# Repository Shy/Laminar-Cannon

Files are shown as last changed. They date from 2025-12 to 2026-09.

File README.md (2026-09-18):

# Laminar Cannon

A person-tracking air purifier that automatically aims filtered air at people using computer vision and pan/tilt servos.

## Highlights

- 🎯 Real-time person tracking with YOLO11 pose detection, aimed at the head
- 🌀 Automatically directs HEPA-filtered air toward detected people
- 🤖 Distributed workflow orchestration with Temporal
- 🎮 Raspberry Pi Zero 2 W drives the servos over I2C
- 📹 Works with a standard Pi Camera Module

## Overview

The Laminar Cannon detects people in real time and mechanically aims fans through a HEPA filter to direct clean air at them. A worker on a laptop runs pose detection while a Raspberry Pi captures frames and drives pan/tilt servos, with Temporal coordinating the two.

Inspired by PC fan powered airpurifiers, this project started with an excellent base by forking from the [Nukit Laminar Cannon](https://github.com/opennukit/Nukit-Laminar-Cannon/). This is a from-scratch build using off-the-shelf components, that I mostly had in my apartment, using python person detection rather than expensive camera eqipment. Nukit has a lot of great information about why this style of airpurifier is effective and I'll defer to them, rather than repeating it.

**Cost:** ~$180-230 in parts

## How It Works

1. A long-running `TrackPerson` workflow loops, starting one `TrackFrame` child workflow per frame
2. The Pi captures a 768x432 frame and returns it as JPEG bytes
3. The laptop runs YOLO11-pose and reports where the person's head is, as an offset from frame centre
4. The workflow converts that offset into a relative servo move
5. The Pi applies the move and reads the resulting angles back off the servo driver

Roughly 1 second per frame when the camera is already centred, 2 seconds when it has to move.

Pose detection is used rather than plain face or body detection so the camera can aim at the **head** specifically. A standing person's bounding-box centre sits around the waist, which frames them with their head near the top edge of the shot.

### Why Temporal?

The Pi Zero 2 W can't run YOLO detection locally - it would take 10+ seconds per frame. By offloading detection to a Temporal workflow on a more powerful machine:

- **Pi stays lightweight** - it only serves camera and servo activities
- **Fast detection** - YOLO runs on laptop hardware in about 100 ms
- **Scalable** - add more Pi units tracking different areas, all using the same detection worker
- **Reliable** - a failed frame costs one frame, not the tracker; the loop counts it and carries on

One detection worker can support dozens of tracking units.

Worth being honest about the fit: Temporal adds tens to hundreds of milliseconds per activity, so this is the wrong tool for a tight, high-rate control loop. At roughly one frame per second it fits comfortably, and durable execution across two very different machines is the interesting part.

## Hardware

- Raspberry Pi Zero 2 W + Camera Module 3 (IMX708)
- Adafruit 16-Channel PWM Servo Bonnet (PCA9685, I2C `0x40`)
- 1x 25 kg-cm servo (tilt) and 1x 20 kg-cm 270° servo (pan)
- 2x high static pressure 120 mm 12 V fans (>2.2 mm H₂O static pressure)
- 12 V to 5-6 V buck converter, **rated 8 A or more**
- 12 V / 5 A power supply
- Levoit Core 200S HEPA Filter

### Things that will bite you

**Size the buck converter properly.** Each servo can pull 2-3 A stalled. A common LM2596 module is 2-3 A total and will brown out mid-sweep - the Pi reboots or the I2C bus drops out. Use an XL4016-class module instead, and put a 1000 µF capacitor across `V+`/`GND` at the bonnet.

**Never feed 12 V to the bonnet's `V+`.** These servos are rated 4.8-6.8 V. Over-volting them causes them to hunt and shake while holding position, which looks exactly like a software problem and is not.

**Clamp the base.** These servos produce far more torque than a light camera needs, and the surplus goes into the mount as reaction torque. A wide fast swing will tip a free-standing rig over. Travel is capped at ±45° per axis in software and the slew rate is deliberately limited, but neither substitutes for clamping it down. Don't ask me how I know. Twice.

### Wiring

Servo power comes from the buck converter; the fans run straight off 12 V. One supply feeds everything.

```
12V 5A supply ──┬── 12V ─────────────────── Fan 1 + / Fan 2 +
                │                           (always on, not switched)
                ├── buck 12V→5-6V (8A+) ─── Bonnet V+ / GND
                │                           + 1000µF cap at the bonnet
                └── GND ────────────────┬── common ground
                                        └── Fan 1 - / Fan 2 -

Pi USB 5V ────── Raspberry Pi ── I2C (GPIO 2/3) ── Servo Bonnet
                      │                                  ├── Ch 0 ──► Tilt servo
                      │                                  └── Ch 1 ──► Pan servo
                      └── CSI ── Camera Module 3
```

Servo connectors are the usual three wires: **brown → GND, red → V+, yellow → PWM**. The bonnet's header rows are silkscreened `GND` / `V+` / `PWM`; line the brown wire up with `GND`. Getting red and brown swapped kills a servo instantly.

**Channel 0 is tilt and channel 1 is pan**, which is the opposite of what you might expect. That mapping came from commanding each axis on the assembled rig and seeing which way the picture moved, so check yours rather than trusting this.

## Software

Two workers. The laptop hosts both workflows plus pose detection; the Pi serves only camera and servo activities. They find each other through Temporal, so they never need to reach each other directly - which also means conference wifi client isolation can't break it.

### Prerequisites

- Python 3.13 on both machines (pinned in `.python-version`)
- [uv](https://docs.astral.sh/uv/) on both machines
- A Temporal Cloud namespace and API key, or adapt `src/purifier/client.py` for a local dev server
- I2C enabled on the Pi: `sudo raspi-config` → Interface Options → I2C, then reboot
- `rpicam-apps` on the Pi (ships with Raspberry Pi OS). Confirm the camera with `rpicam-still --list-cameras`

### Configuration

```bash
cp .env.example .env
```

```bash
TEMPORAL_ADDRESS=your-namespace.tmprl.cloud:7233
TEMPORAL_NAMESPACE=your-namespace.your-account
TEMPORAL_API_KEY=your-api-key
```

The same `.env` is needed on the Pi; `just pi-deploy` copies it across. It is gitignored - keep it that way.

Set the Pi's hostname at the top of the `justfile` (`pi_host`), or add a `Host` entry to your `~/.ssh/config`.

### Running

On the laptop:

```bash
just sync          # install deps, including torch and ultralytics
just worker-mac    # hosts both workflows and pose detection
```

On the Pi, from the laptop:

```bash
just pi-bootstrap          # one time: installs uv
just pi-deploy             # rsync the code and sync dependencies
just pi-worker-fg          # run the worker in the foreground
```

For something that survives a reboot, install the systemd unit instead (needs sudo on the Pi):

```bash
just pi-install-service
just pi-logs
```

Then drive the loop from the laptop:

```bash
just frames 1      # a single frame, the quickest end-to-end check
just start         # run continuously
just status        # frames processed, last action, current state
just stop          # finish the current frame and exit cleanly
```

`just stop` signals the workflow rather than terminating it, so the frame in flight completes and the servos are never abandoned mid-ramp.

## Calibrating the hardware

Check the camera on its own:

```bash
python3 camera_test.py --list          # confirm the sensor is detected
python3 camera_test.py                 # capture to ~/captures/
python3 camera_test.py --rotation 0    # raw sensor orientation
```

The camera module is mounted inverted here, so captures are rotated 180° in the libcamera pipeline. If yours is the right way up, set `CAPTURE_ROTATION_DEGREES` to `0` in `src/purifier/hardware.py`.

Servos, from the laptop:

```bash
just pi-servo-read           # angles read back off the PCA9685 registers
just pi-servo-centre         # centre both axes
just pi-servo-nudge 10 0     # relative move: pan +10°, tilt 0
just pi-servo-release        # stop driving, servos go limp
```

To establish your own direction signs: capture a frame, nudge one axis by a known amount, capture again, and see which way the picture moved. If the camera turns away from the person instead of toward them, flip `PAN_DIRECTION` or `TILT_DIRECTION` in `src/purifier/shared.py`.

The tracking gain lives in the same file. `PROPORTIONAL_GAIN` is deliberately below 1.0 so the camera undershoots and settles; at or above 1.0 it hunts around the target. `PAN_DEGREES_PER_OFFSET` and `TILT_DEGREES_PER_OFFSET` are measured on this rig and will differ on yours.

## Tests

```bash
just check    # ruff and mypy
uv run pytest
```

The workflow tests run against a real Temporal test server with stubbed hardware, so they exercise the actual serialisation path. Detection tests need a fixture image with a person in it under `tests/fixtures/`; they skip cleanly when it is absent.

## Project layout

```
3D/                          CAD for the printed parts (STEP and 3MF)
src/purifier/
  workflows.py               TrackPerson parent loop, TrackFrame child, control law
  activities_pi.py           capture_frame, move_servos, read_servo_angles
  activities_mac.py          detect_person (YOLO11-pose)
  camera.py                  persistent rpicam-still process
  pca9685.py                 servo driver over smbus2
  hardware.py                servo calibration and camera settings
  shared.py                  data contracts and tuning constants
  tracker.py                 start / stop / status CLI
  servo_tool.py              servo diagnostics and calibration CLI
camera_test.py               standalone camera check
deploy/                      systemd unit for the Pi worker
DESIGN.md                    why things are built the way they are
```

`DESIGN.md` is worth a read before changing anything: it records the measurements behind the tuning constants and several traps that cost real debugging time.

## Known gaps

- **Fan control was dropped.** An earlier version drove the fans from the Pi's hardware PWM and switched them off five seconds after the last detection. The current code doesn't touch the fans at all - they're wired straight to 12 V and run constantly. Re-adding this needs a MOSFET on a Pi PWM pin, since the PCA9685 shares one prescaler across all channels and can't produce the 25 kHz a 4-wire fan expects.
- The camera's focus is fixed, set by `LENS_POSITION_DIOPTRES`. Autofocus needs about 2.5 seconds to lock, which doesn't fit the loop.
- Nobody detected means hold position. There's no search pattern or return-to-centre.
- With several people in frame it tracks the largest bounding box, which is effectively the nearest person. Targets can switch between frames.

## License

Matching the original [Nukit Laminar Cannon](https://github.com/opennukit/Nukit-Laminar-Cannon/). This is also a [GPL-3 project](https://www.gnu.org/licenses/gpl-3.0.en.html).
Feel free to fork and adapt!

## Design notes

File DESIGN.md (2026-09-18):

# Person-Tracking Camera on Temporal

A teaching artifact: a Raspberry Pi Zero 2 W aims a camera at whoever is
standing in front of it, with a MacBook doing the person detection and
Temporal Cloud coordinating the two.

The point is to show durable execution across heterogeneous workers - a
constrained ARM device and a laptop with a GPU - not to build a fast tracker.
Temporal adds tens to hundreds of milliseconds per activity, so a tight
control loop is the wrong use of it. At roughly one frame per second, it fits.

## Architecture

```
Temporal Cloud (API key auth)
  |
  +-- workflow TrackPerson  (parent loop)         queue: purifier-mac
        |  continue-as-new every 50 frames
        |
        +-- workflow TrackFrame  (one per frame)  queue: purifier-mac
              |
              +-- activity capture_frame   queue: purifier-pi   (Pi)
              +-- activity detect_person   queue: purifier-mac  (Mac, YOLO11-pose)
              +-- activity move_servos     queue: purifier-pi   (Pi)
```

A long-running parent loop drives one child workflow per frame. Both
workflows are hosted on the MacBook worker; the Pi serves only camera and
servo activities, which keeps the workflow sandbox off a 415 MB board.

The child-per-frame split is for legibility. Activities inline in the parent
produced a history of hundreds of interleaved events that was unreadable in
the UI; now the parent shows one line per frame and each child holds a short,
self-contained history of exactly three activities. Measured cost of the
split: 0.07-0.14 s per frame, far less than feared.

Servo position is not carried across frames or generations. It is read back
from the PCA9685 registers inside the move activity, so the hardware stays
the single source of truth.

### Superseded: a Schedule per frame

The loop began as a Temporal Schedule firing one `TrackPerson` execution per
tick. It worked, but per-frame workflow startup plus waiting for the next
tick boundary cost about a second a frame and bought nothing. A parent loop
removes both. The Schedule tooling is kept in `purifier.schedule` so the
leftover paused Schedule in Cloud can be inspected or deleted.

## Hardware

| Channel | Device | Axis | Range | Notes |
| --- | --- | ---- | ----- | ----- |
| 0 | 25 kg-cm servo | pan | 180 deg | Stronger servo carries the tilt assembly |
| 1 | 20 kg-cm servo | tilt | 270 deg | Only ~90 deg of travel is used |
| - | Camera Module 3 (IMX708) | - | - | CSI, manual fixed focus |
| 15 | unused | - | - | 12 V fan is wired direct, not switched |

Both servos are wildly overspecified for a ~5 g camera. Torque is irrelevant
here; backlash and deadband are the real problems, so expect jitter and
overshoot at small angles.

## Decisions

| Decision | Choice | Why |
| --- | --- | --- |
| Loop shape | One workflow per frame, via a Schedule | Each history is small and readable end to end; teaches Schedules |
| Overlap policy | `SKIP` | Self-tuning, can never back up. `ALLOW_ALL` would be a bug: two runs would read the same start angles and both apply a delta |
| Servo state | Read back from PCA9685 registers | Keeps each run genuinely stateless. Needs a homing step when registers read zero |
| Capture | `--mode 2304:1296 --width 768 --height 432` | Full sensor field of view at ~691 ms and 33 KB. The naive 640x480 silently crops to half the sensor width |
| Focus | Manual fixed (`--lens-position`) | Faster and deterministic; YOLO does not need a sharp frame. Autofocus needed 2.5 s to lock |
| Transport | JPEG bytes in the Temporal payload | ~33 KB, ~44 KB base64. Small enough that history stays readable |
| Detection | YOLO11-pose on the Mac | Keypoints let it aim at the head, not the bbox center, which frames a standing person badly |
| Target choice | Largest bounding box; no-op when none | Deterministic per frame, needs no state. "Faces whoever is nearest" |
| Control law | Proportional, `Kp ~= 0.5`, 5% deadband, max-step clamp | Deliberately undershoots so a ~1.5 s loop converges without oscillating. Needs no lens FOV data |
| Coordination | Temporal Cloud, API key auth | Immune to conference WiFi client isolation - neither machine needs to reach the other |
| Retries | 3 attempts per activity, 30 s `workflow_execution_timeout` | `SKIP` plus infinite retries deadlocks silently: one stuck run makes every later tick skip |
| Pi deploy | rsync + systemd unit | Worker survives reboots; a dead worker otherwise looks like a Temporal failure |

## Measured, not guessed

On the Pi, two passes, `rpicam-still` with a fresh process each time:

| Capture | Sensor crop | Time | Size |
| --- | --- | ---- | ---- |
| 640x480, naive | 2304x1728 (half width) | ~750 ms | 34 KB |
| 640x360, naive | 3072x1728 (67%) | ~691 ms | 22 KB |
| 640x360 `--mode 2304:1296` | full 4608x2592 | ~697 ms | 23 KB |
| 768x432 `--mode 2304:1296` | full 4608x2592 | ~691 ms | 33 KB |
| 640x360 `--mode 4608:2592` | full | ~1739 ms | 21 KB |
| 640x480, continuous AF, 2 s settle | - | ~2450 ms | 34 KB |

Roughly 600 ms is the floor - that is process startup plus camera open, paid
once per capture.

Per-frame budget: ~700 ms capture, 20-50 ms detection warm, 200-500 ms servo
move, plus Cloud round trips. Expect ~1.5-2 s per frame, so `SKIP` settles on
an effective ~2 s cadence.

## Constraints

- **Never capture while the servos are moving.** Satisfied by construction:
  the activities are sequential within one run, and `SKIP` means runs never
  overlap.
- **Pi RAM is 415 MB total.** Nothing else runs on it. `temporalio` has
  aarch64 wheels, so no Rust compile.
- **Python pinned to 3.13.5 on both sides.** Matches the Pi's system Python
  and sidesteps whether PyTorch has 3.14 wheels.
- **torch must never land on the Pi.** Hence two extras rather than one
  dependency list.
- **The API key lives on the Pi's SD card.** Re-provisioning is part of the
  cost of losing a card.

## Layout

```
pyproject.toml              # requires-python 3.13.5; extras: pi, mac
.env.example                # TEMPORAL_ADDRESS / _NAMESPACE / _API_KEY
src/purifier/
  shared.py                 # dataclasses for activity arguments and returns
  activities_pi.py          # capture_frame, move_servos
  activities_mac.py         # detect_person
  workflows.py              # TrackPerson
  worker_pi.py
  worker_mac.py
  schedule.py               # create or update the Schedule
servo_test.py               # standalone hardware check
camera_test.py              # standalone camera check
```

## Idempotency note worth keeping

If `move_servos` fails partway through a ramp, the servos are left at an
intermediate angle - and that is fine. The next frame reads the actual angles
back off the PCA9685 and computes a fresh delta from wherever they really are.
The hardware is the source of truth, so a partial failure self-corrects on the
next tick rather than needing compensation.

## Found during implementation

Two bugs that the design did not anticipate, both worth keeping in mind:

**EXIF orientation is load-bearing for detection, not cosmetic.** The pose
model is trained on upright people. The same frame scores 0.92 confidence
upright and detects *nothing at all* sideways. Worse, `PIL.Image.open`
ignores the EXIF orientation tag, so embedding the tag at capture is not
enough - `ImageOps.exif_transpose` has to be applied before inference. There
is a regression test for this, because every other part of the system looks
perfectly healthy when it breaks.

A second-order trap: `exif_transpose` swaps width and height for a 90 degree
rotation, so offsets must be normalised against the decoded image's
dimensions, not the ones the Pi reported. Using the Pi's values scales both
axes by the wrong divisor.

**ultralytics monkeypatches `PIL.Image.open`.** Its replacement raises
`ModuleNotFoundError` for the optional `pi_heif` package when a decode fails,
rather than PIL's `UnidentifiedImageError`. Catching only PIL's exception let
that escape as an unexpected error, which Temporal treats as retryable - so a
corrupt payload would burn all three attempts instead of failing fast. The
decode handler is deliberately broad for this reason.

## Hardware lessons, learned the hard way

**Servos were being fed ~11 V against a 4.8-6.8 V rating.** The symptom was
the pan axis shaking while holding position. Two software theories were
plausible and both were wrong: ramp-step quantization (real, and worth fixing
anyway) and control-loop gain. Neither was the cause. Dropping the supply to
5 V stopped it immediately.

Worth remembering as a diagnostic order: servo jitter *while holding* points
at power or the servo, not at the code. Jitter *during motion* is the one that
points at the ramp.

**Reaction torque tipped the stand over.** These servos produce vastly more
torque than a 5 g camera needs, and a fast wide swing puts the surplus into
the mount. Fixed by clamping the base, restricting travel to +/-45 degrees per
axis, and cutting the slew rate.

**The axes were not what the design assumed.** Channel 0 turned out to be
tilt and channel 1 pan, and only one of the two directions was positive. All
three facts came from commanding an axis and looking at the resulting frame -
none of them were knowable in advance.

## Latency, measured

Per-frame breakdown on the parent/child architecture, after the fixes below:

| Stage | Time |
| ----- | ---- |
| `capture_frame` | 0.60 s |
| `detect_person` (warm) | 0.10 s |
| `move_servos` (when needed) | 0.56-0.70 s |
| Child workflow overhead | 0.07-0.15 s |
| **Frame, no move** | **0.94-1.27 s** |
| **Frame with a move** | **1.82-2.18 s** |

The first few frames run 3-9 s while the pose weights load and the camera
opens for the first time. That is warmup, not steady state.

**Activities must be synchronous, not `async def`.** The Pi activities block
on `subprocess.run` and `time.sleep`. Declared `async`, that blocking runs
inside the worker's event loop and stalls the SDK's own task handling:
`capture_frame` measured 2.19 s against a bare `rpicam-still` time of 0.74 s.
Making them ordinary `def` and giving the worker a single-threaded executor
brought it to 0.96 s - about 1.2 s a frame recovered. One thread, not more,
because there is one camera and one I2C bus.

**The camera process is kept open, not started per frame.** Starting
`rpicam-still` fresh cost 0.96 s, nearly all of it process startup and opening
the sensor. In signal mode the process stays running and captures on SIGUSR1:
measured 0.31 s from signal to a complete file, 0.60 s as the whole activity
including the base64 encode and the completion round trip. Auto-exposure also
runs continuously now, so frames are better exposed than a fixed per-capture
warm-up allowed.

One trap worth recording: **SIGUSR1's default disposition is to terminate.**
Signalling before rpicam-still installs its handler kills the process every
time, so startup waits for a readiness marker in the process log before the
first signal. The log goes to a file, not a pipe - an undrained pipe fills and
blocks the camera process outright.

### Servo ramp rate, and why it moved around

| Setting | Pan | Tilt | Reason |
| --- | --- | ---- | --- |
| 2.0 deg / 20 ms | 100 deg/s | 100 deg/s | Original |
| 1.0 deg / 50 ms | 20 deg/s | 20 deg/s | Stand tipped over from reaction torque |
| 1 count / 40 ms | 16.5 deg/s | 11 deg/s | Degree steps landed as uneven 1-then-2 count jumps |
| 1 count / 20 ms | 33 deg/s | 22 deg/s | First latency pass |
| **2 counts / 20 ms** | **66 deg/s** | **44 deg/s** | Current; `move_servos` 0.9 s -> 0.62 s |

Step timing cannot go below one PWM period (20 ms) without targets arriving
mid-servo-frame, so speed comes from step size, not step rate. The axes differ
because one count is 0.659 deg on the 270 deg pan servo but 0.440 deg on the
180 deg tilt servo.

The caution in the slower numbers is partly historical: 100 deg/s was only
ever shown to tip a *free-standing* mount. The base is clamped now, travel is
capped at +/-45 deg per axis, and the servos are no longer over-volted.

## Open items

- Is the pan/tilt mount built, with the camera physically on the servos?
  Until it is, the loop can be tested end to end against a stationary camera -
  servo commands will execute and read back correctly, they just will not
  change the view.
- The camera is being remounted so the frame is natively upright. After that,
  set `CAPTURE_ORIENTATION` in `src/purifier/hardware.py` and
  `MOUNTED_ORIENTATION` in `camera_test.py` to `1`. Pixel-x then maps to pan
  and pixel-y to tilt with no rotation in the path at all. Mounted sideways
  the axes swap and every sign error gets twice as confusing.
- `PAN_DIRECTION` and `TILT_DIRECTION` in `shared.py` are guesses. If the
  camera turns away from the person instead of toward them, flip the sign.
- Test fixtures are untracked: they are photos of a real person. Either commit
  them deliberately or swap in a public-domain image, then drop the
  `tests/fixtures/*.jpg` line from `.gitignore`.
- A paused Schedule named `track-person-loop` still exists in Cloud from the
  superseded design. It is harmless while paused, but unpausing it would now
  start a fresh long-running loop every couple of seconds. Remove it with
  `just schedule-delete` once nothing else needs it.
- The systemd unit in `deploy/` is written but not installed: that needs
  sudo on the Pi. The worker currently runs detached by hand, so it will not
  survive a reboot.
- `Kp`, the deadband and the max-step clamp all need tuning against real
  hardware. They are constants in one place for that reason.
- Servo move duration is an estimate; it was never measured, because the
  servos were unplugged throughout.

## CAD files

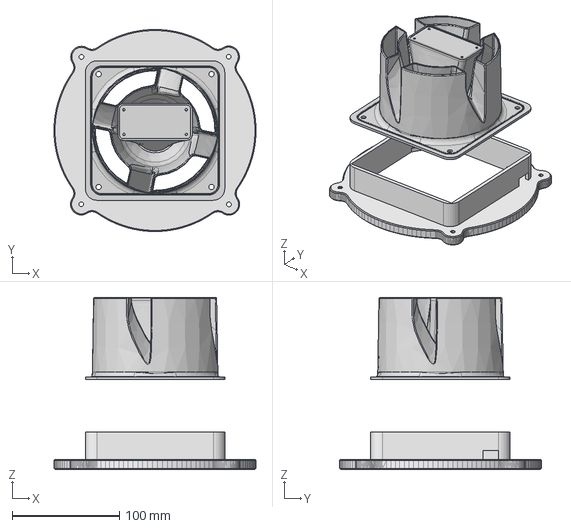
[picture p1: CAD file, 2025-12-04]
3D/Laminar Cannon Front.step
187.9 x 187.9 x 160.1 mm

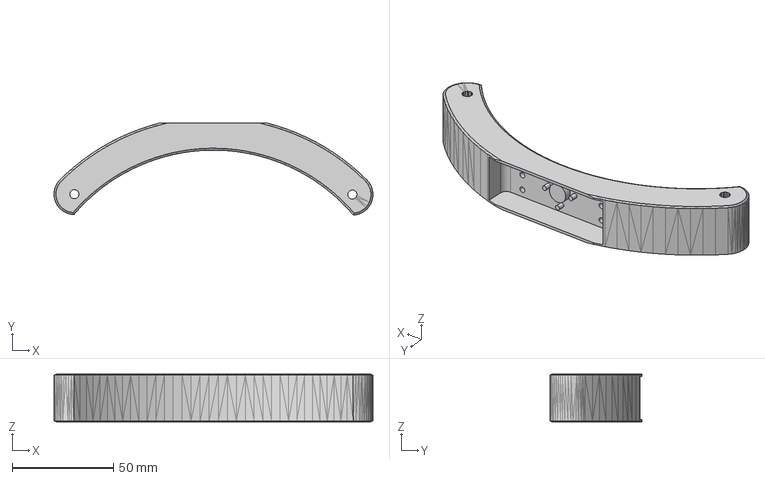
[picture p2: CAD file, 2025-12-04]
3D/Laminar Canon Cradle.step
157.2 x 45.5 x 23.5 mm

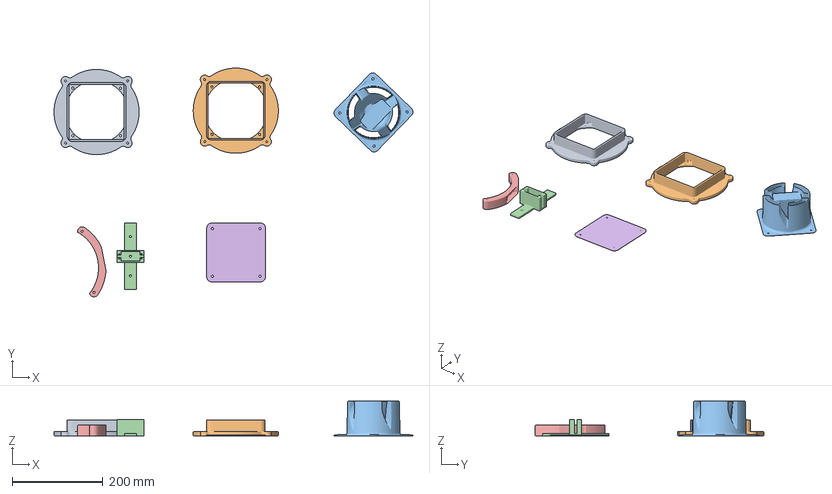
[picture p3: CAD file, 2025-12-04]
3D/Laminar Canon.3mf
792.6 x 505.1 x 76.4 mm
Laminar Cannon Front base x 2
Laminar Cannon Front Top
2020 Servo Mount
Cradle
Laminar Cannon Back Plate 120mm (1).stl

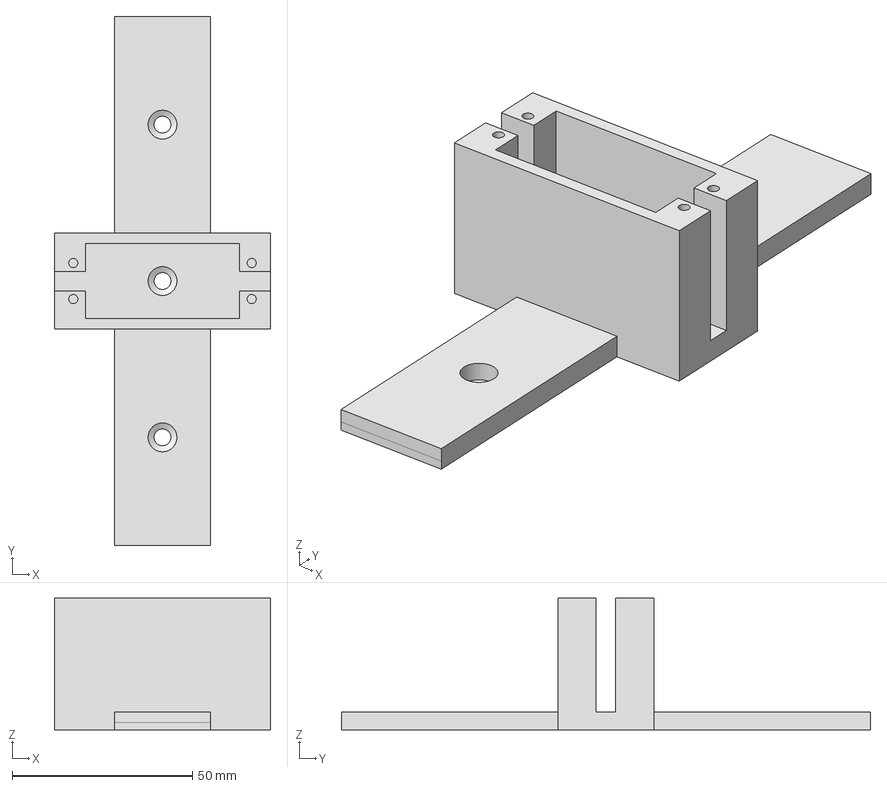
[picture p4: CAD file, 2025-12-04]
3D/Laminar Canon Servo 2020 Mount.step
60.0 x 146.7 x 36.5 mm

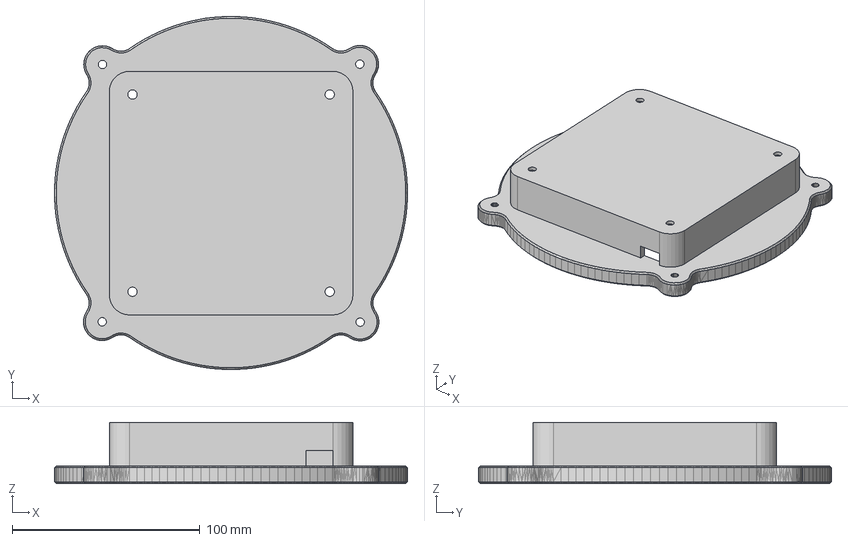
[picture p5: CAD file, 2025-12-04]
3D/Laminar Cannon Back Plate 120mm.step
187.9 x 187.9 x 32.6 mm

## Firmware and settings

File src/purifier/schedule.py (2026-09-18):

"""Create, inspect and control the tracking Schedule.

The Schedule is what makes this loop run: one ``TrackPerson`` execution per
tick, each independent. Two settings here are load-bearing:

* ``overlap=SKIP`` - a tick is dropped if the previous frame is still running,
  so the loop can never back up. ``ALLOW_ALL`` would be a bug, not merely
  inefficient: two concurrent runs would each read the same starting angles
  and both apply a delta, double-moving the servos.
* ``execution_timeout`` - a hard ceiling on one frame. With SKIP, a run that
  hung would make every later tick skip and the loop would stop silently.
  This guarantees that cannot happen.
"""

import argparse
import asyncio
import contextlib
import sys
from datetime import timedelta

from temporalio.client import (
    Client,
    Schedule,
    ScheduleActionStartWorkflow,
    ScheduleAlreadyRunningError,
    ScheduleIntervalSpec,
    ScheduleOverlapPolicy,
    SchedulePolicy,
    ScheduleSpec,
    ScheduleState,
    ScheduleUpdate,
    ScheduleUpdateInput,
)
from temporalio.service import RPCError

from purifier.client import connect
from purifier.shared import (
    MAC_TASK_QUEUE,
    SCHEDULE_ID,
    WORKFLOW_ID_PREFIX,
)

#: How often to attempt a frame. Measured pipeline is ~1.7 s without a servo
#: move and ~3 s with one, so a tick longer than that wastes the difference
#: waiting for the next boundary: a 5 s tick on a 3 s pipeline idled for 2 s
#: every cycle. A 2 s tick with BUFFER_ONE keeps a run queued so frames go
#: back to back at whatever rate the pipeline actually sustains.
TICK_INTERVAL = timedelta(seconds=2)

#: Hard ceiling on a single frame. Must stay below a couple of ticks so a bad
#: frame cannot stall the loop for long.
EXECUTION_TIMEOUT = timedelta(seconds=30)


def build_schedule() -> Schedule:
    """Describe the tracking Schedule.

    :returns: The Schedule definition.
    """
    return Schedule(
        action=ScheduleActionStartWorkflow(
            "TrackPerson",
            id=WORKFLOW_ID_PREFIX,
            task_queue=MAC_TASK_QUEUE,
            execution_timeout=EXECUTION_TIMEOUT,
        ),
        spec=ScheduleSpec(
            intervals=[ScheduleIntervalSpec(every=TICK_INTERVAL)],
        ),
        # BUFFER_ONE, not SKIP: keep exactly one run queued so the next frame
        # starts the moment the current one finishes, rather than waiting for
        # a tick boundary. Still never concurrent, which matters - two
        # overlapping runs would both read the same start angles and each
        # apply a delta, double-moving the servos. ALLOW_ALL remains a bug.
        policy=SchedulePolicy(overlap=ScheduleOverlapPolicy.BUFFER_ONE),
        state=ScheduleState(
            note="Person-tracking camera loop",
            paused=True,
        ),
    )


async def create(client: Client, start_paused: bool) -> None:
    """Create the Schedule, or report that it already exists.

    Created paused by default, so hardware is never commanded the instant the
    Schedule lands. Unpause explicitly once both workers are confirmed up.

    :param client: Connected Temporal client.
    :param start_paused: Whether to leave the Schedule paused.
    """
    definition = build_schedule()
    definition.state.paused = start_paused
    try:
        await client.create_schedule(SCHEDULE_ID, definition)
    except ScheduleAlreadyRunningError:
        print(f"schedule {SCHEDULE_ID!r} already exists; use --update")
        return
    state = "paused" if start_paused else "running"
    print(f"created schedule {SCHEDULE_ID!r} ({state}), tick {TICK_INTERVAL}")


async def update(client: Client) -> None:
    """Replace the existing Schedule's definition with the current code.

    :param client: Connected Temporal client.
    """
    handle = client.get_schedule_handle(SCHEDULE_ID)
    description = await handle.describe()
    was_paused = description.schedule.state.paused

    async def replace(_input: ScheduleUpdateInput) -> ScheduleUpdate:
        # The updater must return a ScheduleUpdate wrapper, not a bare
        # Schedule; returning the Schedule itself trips an assertion inside
        # the SDK with no useful message.
        definition = build_schedule()
        definition.state.paused = was_paused
        return ScheduleUpdate(schedule=definition)

    await handle.update(replace)
    print(f"updated schedule {SCHEDULE_ID!r} (paused={was_paused})")


async def set_paused(client: Client, paused: bool) -> None:
    """Pause or resume the Schedule.

    :param client: Connected Temporal client.
    :param paused: ``True`` to pause, ``False`` to resume.
    """
    handle = client.get_schedule_handle(SCHEDULE_ID)
    if paused:
        await handle.pause(note="paused by schedule.py")
        print(f"paused {SCHEDULE_ID!r}")
    else:
        await handle.unpause(note="resumed by schedule.py")
        print(f"resumed {SCHEDULE_ID!r}")


async def describe(client: Client) -> None:
    """Print the Schedule's current state and recent actions.

    :param client: Connected Temporal client.
    """
    handle = client.get_schedule_handle(SCHEDULE_ID)
    description = await handle.describe()
    state = description.schedule.state
    info = description.info

    print(f"schedule:        {SCHEDULE_ID}")
    print(f"paused:          {state.paused}")
    print(f"tick:            {TICK_INTERVAL}")
    print(f"overlap:         {description.schedule.policy.overlap.name}")
    print(f"running now:     {len(info.running_actions)}")
    print(f"actions taken:   {info.num_actions}")
    print(f"actions skipped: {info.num_actions_skipped_overlap}")
    if info.recent_actions:
        print("recent:")
        for action in info.recent_actions[-5:]:
            started = action.started_at.isoformat(timespec="seconds")
            execution = action.action
            workflow_id = getattr(execution, "workflow_id", "?")
            print(f"  {started}  {workflow_id}")


async def delete(client: Client) -> None:
    """Delete the Schedule.

    :param client: Connected Temporal client.
    """
    handle = client.get_schedule_handle(SCHEDULE_ID)
    await handle.delete()
    print(f"deleted {SCHEDULE_ID!r}")


async def trigger(client: Client) -> None:
    """Run one frame immediately, regardless of pause state.

    The fastest way to check the whole pipeline end to end without letting the
    loop run continuously.

    :param client: Connected Temporal client.
    """
    handle = client.get_schedule_handle(SCHEDULE_ID)
    await handle.trigger(overlap=ScheduleOverlapPolicy.SKIP)
    print(f"triggered one frame on {SCHEDULE_ID!r}")


def parse_args(argv: list[str] | None = None) -> argparse.Namespace:
    """Parse command line arguments.

    :param argv: Argument list, defaulting to ``sys.argv[1:]``.
    :returns: Parsed arguments.
    """
    parser = argparse.ArgumentParser(description=__doc__)
    group = parser.add_mutually_exclusive_group(required=True)
    group.add_argument("--create", action="store_true", help="create the schedule")
    group.add_argument("--update", action="store_true", help="push definition changes")
    group.add_argument("--start", action="store_true", help="resume the schedule")
    group.add_argument("--stop", action="store_true", help="pause the schedule")
    group.add_argument("--status", action="store_true", help="show current state")
    group.add_argument("--trigger", action="store_true", help="run one frame now")
    group.add_argument("--delete", action="store_true", help="delete the schedule")
    parser.add_argument(
        "--unpaused",
        action="store_true",
        help="with --create, start running immediately instead of paused",
    )
    return parser.parse_args(argv)


async def main() -> None:
    """Entry point."""
    args = parse_args()
    client = await connect()

    try:
        if args.create:
            await create(client, start_paused=not args.unpaused)
        elif args.update:
            await update(client)
        elif args.start:
            await set_paused(client, paused=False)
        elif args.stop:
            await set_paused(client, paused=True)
        elif args.status:
            await describe(client)
        elif args.trigger:
            await trigger(client)
        elif args.delete:
            await delete(client)
    except RPCError as rpc_error:
        raise SystemExit(f"Temporal rejected the call: {rpc_error}") from rpc_error


if __name__ == "__main__":
    with contextlib.suppress(KeyboardInterrupt):
        sys.exit(asyncio.run(main()))

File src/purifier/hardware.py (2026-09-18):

"""Servo and camera hardware definitions for the Pi, and the angle maths.

This module is the single home for the servo calibration constants. The
diagnostic CLI in :mod:`purifier.servo_tool` imports them from here, so there
is exactly one place to retune pulse widths.

The PCA9685's duty-cycle registers are the source of truth for servo position.
Reading them back is what lets every scheduled workflow be stateless, so the
conversions here are the load-bearing part of that design.
"""

from dataclasses import dataclass

#: I2C address of the Servo Bonnet with no address jumpers soldered.
BONNET_I2C_ADDRESS = 0x40

#: Standard hobby servo update rate, in Hz.
SERVO_FREQUENCY_HZ = 50

#: PCA9685 internal oscillator, in Hz.
REFERENCE_CLOCK_HZ = 25_000_000

#: PWM period at :data:`SERVO_FREQUENCY_HZ`, in microseconds.
PWM_PERIOD_US = 1_000_000 // SERVO_FREQUENCY_HZ

#: Full scale of the PCA9685's 16-bit duty cycle representation.
DUTY_CYCLE_FULL_SCALE = 0xFFFF


@dataclass(frozen=True)
class ServoSpec:
    """Calibration for one servo channel.

    :param channel: PCA9685 output channel index.
    :param name: Label used in logs and activity results.
    :param actuation_range: Total mechanical travel in degrees.
    :param min_pulse_us: Pulse width in microseconds at 0 degrees.
    :param max_pulse_us: Pulse width in microseconds at ``actuation_range``.
    :param min_angle: Lowest angle this axis is allowed to reach.
    :param max_angle: Highest angle this axis is allowed to reach.
    """

    channel: int
    name: str
    actuation_range: int
    min_pulse_us: int
    max_pulse_us: int
    min_angle: float
    max_angle: float

    @property
    def centre_angle(self) -> float:
        """Midpoint of the permitted travel, used as the home position.

        :returns: Angle halfway between ``min_angle`` and ``max_angle``.
        """
        return (self.min_angle + self.max_angle) / 2

    def clamp(self, angle: float) -> float:
        """Limit an angle to this axis's permitted travel.

        :param angle: Requested angle in degrees.
        :returns: Angle clamped to ``min_angle..max_angle``.
        """
        return max(self.min_angle, min(self.max_angle, angle))

    def angle_to_pulse_us(self, angle: float) -> float:
        """Convert an angle to its pulse width.

        :param angle: Angle in degrees, within the actuation range.
        :returns: Pulse width in microseconds.
        """
        span = self.max_pulse_us - self.min_pulse_us
        return self.min_pulse_us + span * (angle / self.actuation_range)

    def pulse_us_to_angle(self, pulse_us: float) -> float:
        """Convert a pulse width back to an angle.

        :param pulse_us: Pulse width in microseconds.
        :returns: Angle in degrees, not clamped, so an out-of-range register
            value is visible to the caller rather than silently corrected.
        """
        span = self.max_pulse_us - self.min_pulse_us
        return (pulse_us - self.min_pulse_us) / span * self.actuation_range


#: Tilt axis: channel 0, the 25 kg-cm 180 degree servo.
#:
#: This is NOT the axis the design originally assigned to channel 0. Measured
#: on the assembled rig: commanding channel 0 pitches the camera up and down.
#: The build decided the mapping, so the code follows the build.
#:
#: Travel is restricted to +/-45 degrees around centre. The servo can do far
#: more, but a wide fast swing puts enough reaction torque into the mount to
#: topple the stand - which is not hypothetical, it happened.
TILT_SERVO = ServoSpec(
    channel=0,
    name="tilt",
    actuation_range=180,
    min_pulse_us=500,
    max_pulse_us=2500,
    min_angle=45.0,
    max_angle=135.0,
)

#: Pan axis: channel 1, the 20 kg-cm 270 degree servo.
#:
#: Measured: commanding channel 1 rotates the camera left and right. Given the
#: same +/-45 degree window around centre as tilt, so both axes behave alike
#: and neither can swing far enough to unbalance the mount.
PAN_SERVO = ServoSpec(
    channel=1,
    name="pan",
    actuation_range=270,
    min_pulse_us=500,
    max_pulse_us=2500,
    min_angle=90.0,
    max_angle=180.0,
)

# --- Camera ------------------------------------------------------------------

#: Capture helper shipped with Raspberry Pi OS.
RPICAM_STILL = "rpicam-still"

#: Forced sensor mode. Without this, libcamera picks the cropped 1536x864 mode
#: for small outputs and silently throws away up to half the horizontal field
#: of view, which makes the tracker lose people far sooner.
SENSOR_MODE = "2304:1296"

#: Capture size. Full field of view at ~800 ms. JPEG size tracks scene detail,
#: not dimensions: ~33 KB of blank wall, ~110 KB of a real cluttered room
#: (~147 KB once base64-encoded). Wider output costs payload, not time.
CAPTURE_WIDTH = 768
CAPTURE_HEIGHT = 432

#: Fixed focus distance in dioptres (~0.63 m). Autofocus needs ~2.5 s to lock,
#: which does not fit the loop, and pose detection tolerates a soft frame.
LENS_POSITION_DIOPTRES = 1.6
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

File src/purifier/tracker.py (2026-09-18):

"""Start, stop and inspect the tracking loop.

Replaces the Schedule-based control in ``purifier.schedule``. The loop is now
a single long-running workflow, so starting it is one workflow start and
stopping it is a signal, rather than a Schedule that had to be created,
updated, paused and resumed.

Stopping uses a signal rather than termination on purpose: the workflow
finishes the frame it is on, so the servos are never abandoned mid-ramp.
"""

import argparse
import asyncio
import contextlib
import sys

from temporalio.client import Client, WorkflowExecutionStatus, WorkflowHandle
from temporalio.service import RPCError

from purifier.client import connect
from purifier.shared import (
    MAC_TASK_QUEUE,
    TrackerConfig,
    TrackerState,
    TrackerStatus,
)
from purifier.workflows import TrackPerson

#: Stable workflow ID, so stop and status need no run ID.
TRACKER_WORKFLOW_ID = "track-person-loop"


async def _running_handle(
    client: Client,
) -> WorkflowHandle[TrackPerson, TrackerState] | None:
    """Return a handle to the running loop, if there is one.

    :param client: Connected Temporal client.
    :returns: The handle, or ``None`` if the loop is not running.
    """
    handle = client.get_workflow_handle(TRACKER_WORKFLOW_ID)
    try:
        description = await handle.describe()
    except RPCError:
        return None
    if description.status == WorkflowExecutionStatus.RUNNING:
        return handle
    return None


async def start(client: Client, config: TrackerConfig) -> None:
    """Start the tracking loop, unless it is already running.

    :param client: Connected Temporal client.
    :param config: Loop parameters.
    """
    if await _running_handle(client) is not None:
        print(f"{TRACKER_WORKFLOW_ID!r} is already running; use --status or --stop")
        return

    handle = await client.start_workflow(
        TrackPerson.run,
        args=[config, None],
        id=TRACKER_WORKFLOW_ID,
        task_queue=MAC_TASK_QUEUE,
    )
    budget = (
        "until stopped"
        if config.stop_after_frames is None
        else f"for {config.stop_after_frames} frames"
    )
    print(f"started {TRACKER_WORKFLOW_ID!r} ({budget}), run {handle.result_run_id}")
    print(f"  continue-as-new every {config.frames_per_run} frames")


async def stop(client: Client) -> None:
    """Signal the loop to finish its current frame and exit.

    :param client: Connected Temporal client.
    """
    handle = await _running_handle(client)
    if handle is None:
        print(f"{TRACKER_WORKFLOW_ID!r} is not running")
        return
    await handle.signal(TrackPerson.stop)
    print(f"stop signalled; {TRACKER_WORKFLOW_ID!r} will exit after the current frame")


async def status(client: Client) -> None:
    """Query and print the loop's progress.

    :param client: Connected Temporal client.
    """
    handle = client.get_workflow_handle(TRACKER_WORKFLOW_ID)
    try:
        description = await handle.describe()
    except RPCError:
        print(f"{TRACKER_WORKFLOW_ID!r} has never run")
        return

    print(f"workflow:  {TRACKER_WORKFLOW_ID}")
    print(f"status:    {description.status.name if description.status else 'unknown'}")

    if description.status != WorkflowExecutionStatus.RUNNING:
        return

    # Passing the method reference lets the SDK infer the result type, so no
    # result_type is needed here - unlike the string-dispatched activities.
    snapshot: TrackerStatus = await handle.query(TrackPerson.status)
    state = snapshot.state
    print(f"generation:        {state.generation}")
    print(f"frames processed:  {state.frames_processed}")
    print(f"  moved:           {state.moves_made}")
    print(f"  no person:       {state.frames_without_person}")
    print(f"  failed:          {state.frames_failed}")
    print(f"last action:       {snapshot.last_action}")
    if snapshot.last_note:
        print(f"last note:         {snapshot.last_note}")
    if snapshot.stopping:
        print("stop requested, finishing current frame")


def parse_args(argv: list[str] | None = None) -> argparse.Namespace:
    """Parse command line arguments.

    :param argv: Argument list, defaulting to ``sys.argv[1:]``.
    :returns: Parsed arguments.
    """
    parser = argparse.ArgumentParser(description=__doc__)
    mode = parser.add_mutually_exclusive_group(required=True)
    mode.add_argument("--start", action="store_true", help="start the loop")
    mode.add_argument("--stop", action="store_true", help="signal it to exit")
    mode.add_argument("--status", action="store_true", help="query progress")

    parser.add_argument(
        "--frames",
        type=int,
        metavar="N",
        help="with --start, run N frames then exit (default: until stopped)",
    )
    parser.add_argument(
        "--frames-per-run",
        type=int,
        default=TrackerConfig.frames_per_run,
        metavar="N",
        help=(
            "with --start, frames before continue-as-new "
            f"(default {TrackerConfig.frames_per_run}); bounds history size"
        ),
    )
    parser.add_argument(
        "--pause",
        type=float,
        default=TrackerConfig.frame_pause_seconds,
        metavar="SECONDS",
        help="with --start, pause between frames (default 0, run flat out)",
    )
    return parser.parse_args(argv)


async def main() -> None:
    """Entry point."""
    args = parse_args()
    client = await connect()

    try:
        if args.start:
            await start(
                client,
                TrackerConfig(
                    frames_per_run=args.frames_per_run,
                    frame_pause_seconds=args.pause,
                    stop_after_frames=args.frames,
                ),
            )
        elif args.stop:
            await stop(client)
        elif args.status:
            await status(client)
    except RPCError as rpc_error:
        raise SystemExit(f"Temporal rejected the call: {rpc_error}") from rpc_error


if __name__ == "__main__":
    with contextlib.suppress(KeyboardInterrupt):
        sys.exit(asyncio.run(main()))

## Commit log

2025-07-07 Pushed up 120mm fan first draft
2025-08-04 Updated 3d files to make it easier for folks to change
    [Laminar Cannon Back Plate 120mm.3mf, Laminar Cannon Back Plate 120mm.f3d, Laminar Cannon Back Plate 120mm.step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]
2025-12-04 Commited most functional version
    [Laminar Cannon Back Plate 120mm.3mf, Laminar Cannon Back Plate 120mm.f3d, Laminar Cannon Back Plate 120mm.step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]
2026-09-18 Replace the Flask/Pi code with the Temporal Cloud tracking loop
    Keeps the 3D models, the GPL-3 licence, and the README's background - the
    Nukit attribution, the cost, the reasoning about why this style of purifier
    works - and replaces everything under flask/ and pi/.
    What changed in the design:
    A long-running parent workflow drives one child workflow per frame, rather
    than a Flask endpoint called per capture. One child per frame keeps each
    history short enough to read in the UI while the parent stays a single line
    per frame, and continue-as-new bounds the parent. Coordination is Temporal
    Cloud with API key auth, so neither machine has to reach the other.
    Detection is YOLO11-pose rather th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
    [activities_mac.py, activities_pi.py, camera.py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]
